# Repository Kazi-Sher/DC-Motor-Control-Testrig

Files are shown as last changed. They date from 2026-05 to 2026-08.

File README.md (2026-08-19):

# DC Motor Control Test Rig

A low-cost open-source experimental test rig for DC motor characterization and embedded control. The rig supports reproducible experiments from basic motor modeling to advanced control design.

## Repository Layout
```text
hardware/       Hardware datasheets, wiring diagram, and rig image
firmware/       STM32 firmware, generated embedded code, board-level configuration
matlab/         MATLAB scripts/Simulink models for identification, validation, control
data/           Raw and processed experiment data used to reproduce plots/metrics
results/        Result plots
```

## Roadmap
- [x] Hardware rig assembled
- [x] Position and speed based model validation
- [x] PI speed control
- [x] State-space position control (pole placement + LQR)
- [x] Observer-based estimation (Luenberger + Kalman / LQG)
- [x] Controller comparison (PID, observer-based pole placement, and LQG)

## Test Rig
- STM32 Nucleo-F446RE microcontroller board
- 12 V DC geared motor with quadrature encoder, JGA25-371 class
- IBT-2 / BTS7960 H-bridge motor driver
- ACS712 5 A current sensor
- 12 V DC power supply

<p align="center">
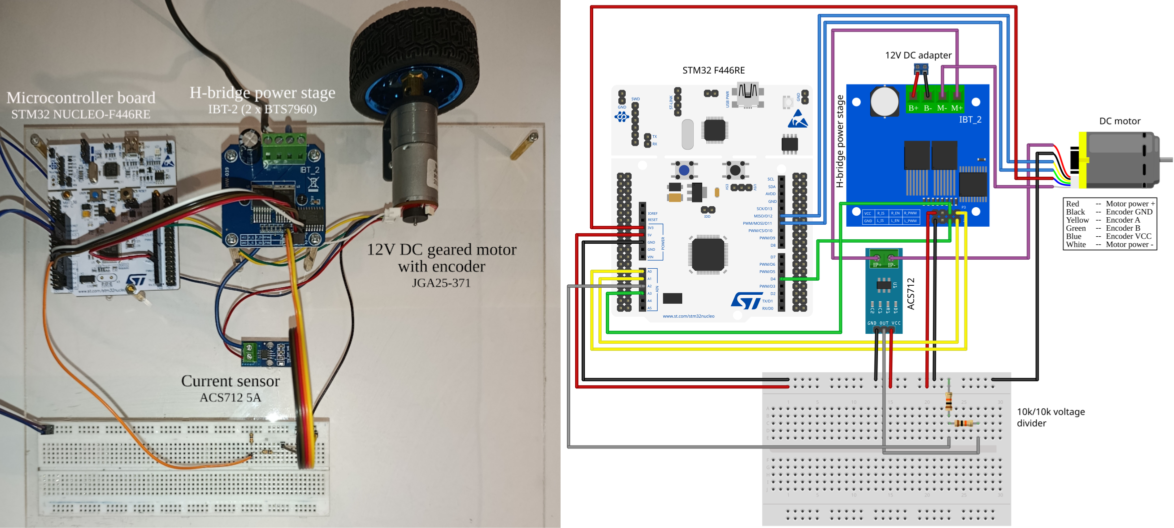
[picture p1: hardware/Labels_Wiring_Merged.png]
Labeled DC motor control test rig
  
</p>

## Motor Identification and Model Validation

Motor parameters were identified by classical lumped-element methods: `R_a` from locked-rotor current; `K` and `b` from steady-state voltage–speed and torque–speed measurements; `J` from a coast-down test.

| Parameter | Value | Note |
|---|---:|---|
| `Ra` | 2.1 Ω | Armature resistance |
| `La` | 100 µH | Armature inductance (assumed for now) |
| `K` | 0.59 V s/rad | Back-EMF / torque constant (output-shaft referred) |
| `J` | 2.03e-3 kg m² | Equivalent inertia (output-shaft referred) |
| `b` | 0.0164 N m s/rad | Viscous friction (output-shaft referred) |

Using these parameters, the model closely matches the measured position response for the voltage-step validation test (`NRMSE = 0.955`, `R^2 = 0.998`).

<p align="center">
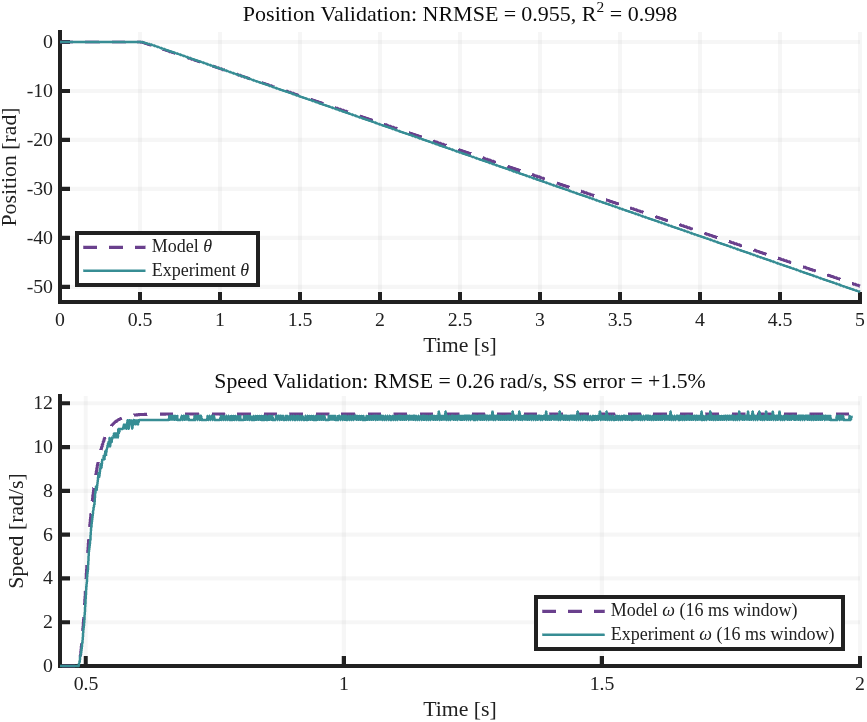
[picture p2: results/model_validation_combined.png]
Open-loop position and speed model validation
  
</p>

The motor was further characterized using an open-loop duty staircase. The identified model was then validated on a separate single-step experiment: a `0.6` duty command applied at `t = 0.5 s`. The model predicts the measured speed response closely:

- RMSE over the step response: `0.26 rad/s`
- Steady-state speed error: `+1.5%`
- Speed estimate: encoder position forward difference with 16 ms window

## PI Speed Control

PI speed control was designed using the experimentally identified first-order speed model of motor:

$$
G(s)=\frac{K_{dc}}{\tau s+1}
$$

where $K_{dc} = 19.524~\text{rad/s/duty}$ and $\tau=0.018~\text{s}$. The controller gains were selected by matching the closed-loop denominator to a second-order target with $\omega_n=50~\text{rad/s}$ and $\zeta=0.9$, giving $K_p = 0.0318$ and $K_i = 2.3049$.

The figure below compares the saturation-aware simulation with the real motor-rig response for a $10~\text{rad/s}$ speed step. The raw embedded speed estimate is shown for transparency, but performance metrics are computed from a 50 ms angle-slope estimate to reduce encoder quantization effects.

Angle-derived experimental metrics:

- Peak speed: $10.51~\text{rad/s}$
- Overshoot: 5.1%
- Rise time: $44~\text{ms}$
- Settling time (2%): $127~\text{ms}$
- Steady-state error: Approx. $3.5e-4~\text{rad/s}$

<p align="center">
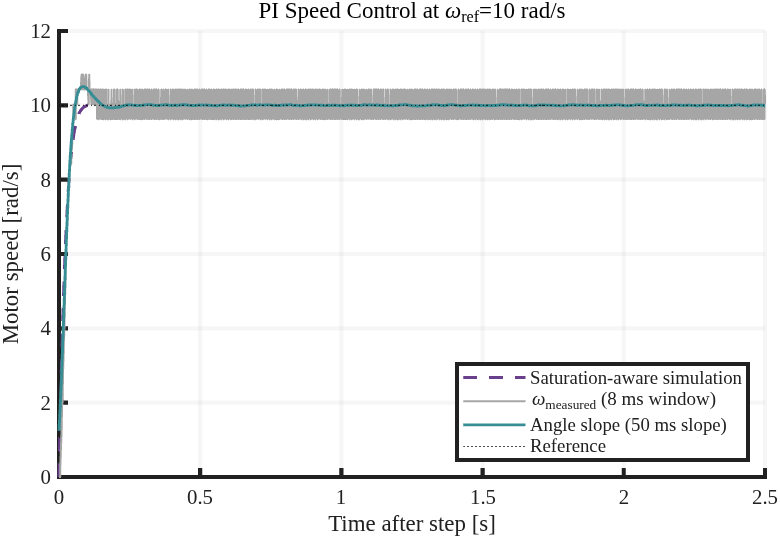
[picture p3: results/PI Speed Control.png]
PI Speed Control
  
</p>

## State-Space Position Control

The PI speed plant was extended to a 2-state position model `x = [θ, ω]ᵀ` and a 3-state form `x_aug = [x_i, θ, ω]ᵀ` with an integrator on the tracking error. Three controller families were designed and deployed with references of 0.20 rad and 0.50 rad:

1. **2-state pole placement (PP2):** `K = [K_θ, K_ω]` plus feedforward `Nbar`
2. **3-state pole placement with integrator (PP3):** `K_aug = [K_i, K_θ, K_ω]`, no `Nbar` since the integrator handles DC tracking
3. **LQR** on the same 3-state plant: gains from `lqr(A_aug, B_aug, Q, R)`

### Pole placement (PP): dead-zone discovery and integrator fix

Without the integrator, the controller stalls before reaching the reference because the residual duty falls below the motor's static-friction threshold. Adding an integrator state eliminates this offset and the saturation-aware simulation tracks the 3-state hardware response within the noise floor.

<p align="center">
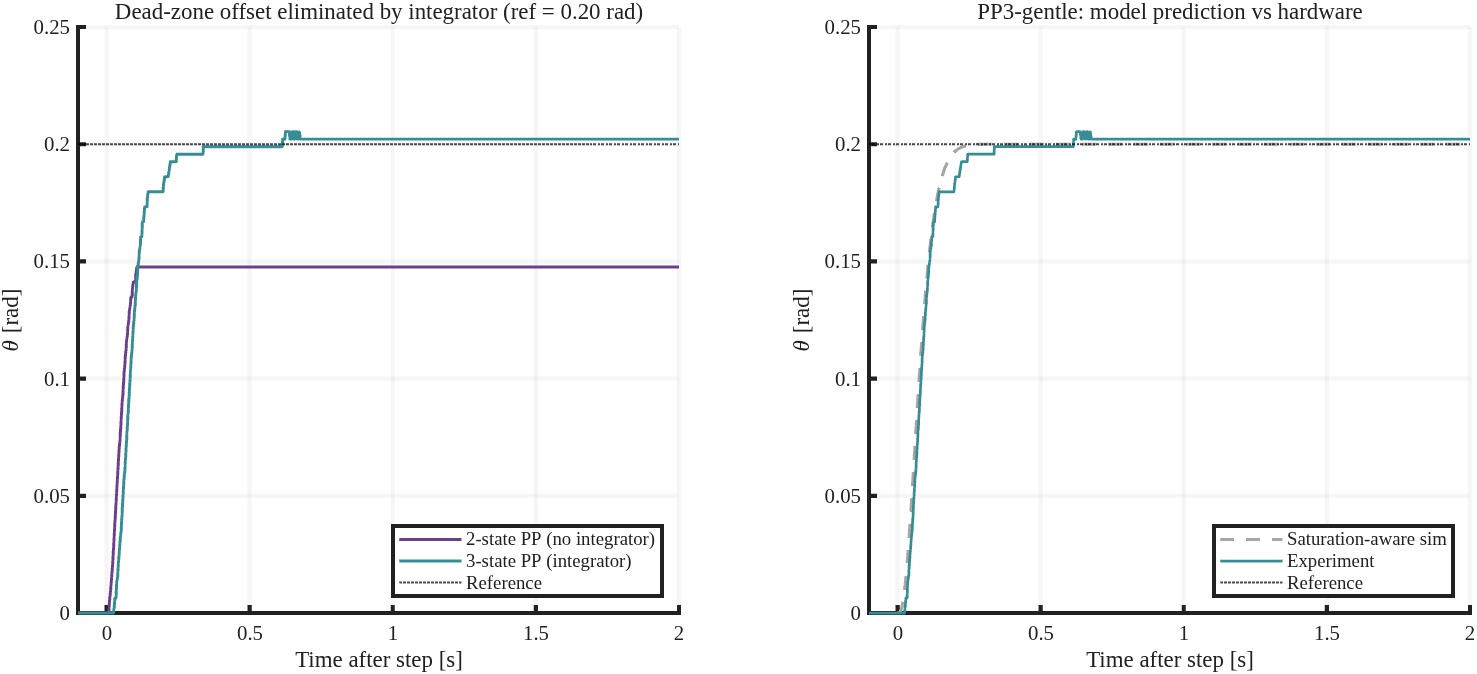
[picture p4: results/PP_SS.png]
State-space pole placement: dead-zone and integrator fix; model vs hardware
  
</p>

Results (reference = 0.20 rad):

- **2-state PP-gentle:** steady-state offset ≈ **26 %** (motor stalls at 0.148 rad)
- **3-state PP-gentle:** steady-state offset ≈ **1 %** (reaches 0.20 rad)
- **Cross-validated motor breakaway threshold:** ≈ **6 % PWM duty**, from residual steady-state command across four PP2 runs
- **Model vs hardware (PP3-gentle):** steady-state match within encoder resolution

### LQR: methodology comparison and a limit-cycle finding

LQR on the same plant chooses gains by minimizing a quadratic cost rather than placing specific poles. Conservative weights produce a clean, low-jitter response but at much lower bandwidth than the equivalent pole-placement design. Aggressive weights raise the bandwidth. But on hardware, the closed loop falls into a sustained limit cycle: position still tracks the reference, but the control effort thrashes between duty saturation rails.

<p align="center">
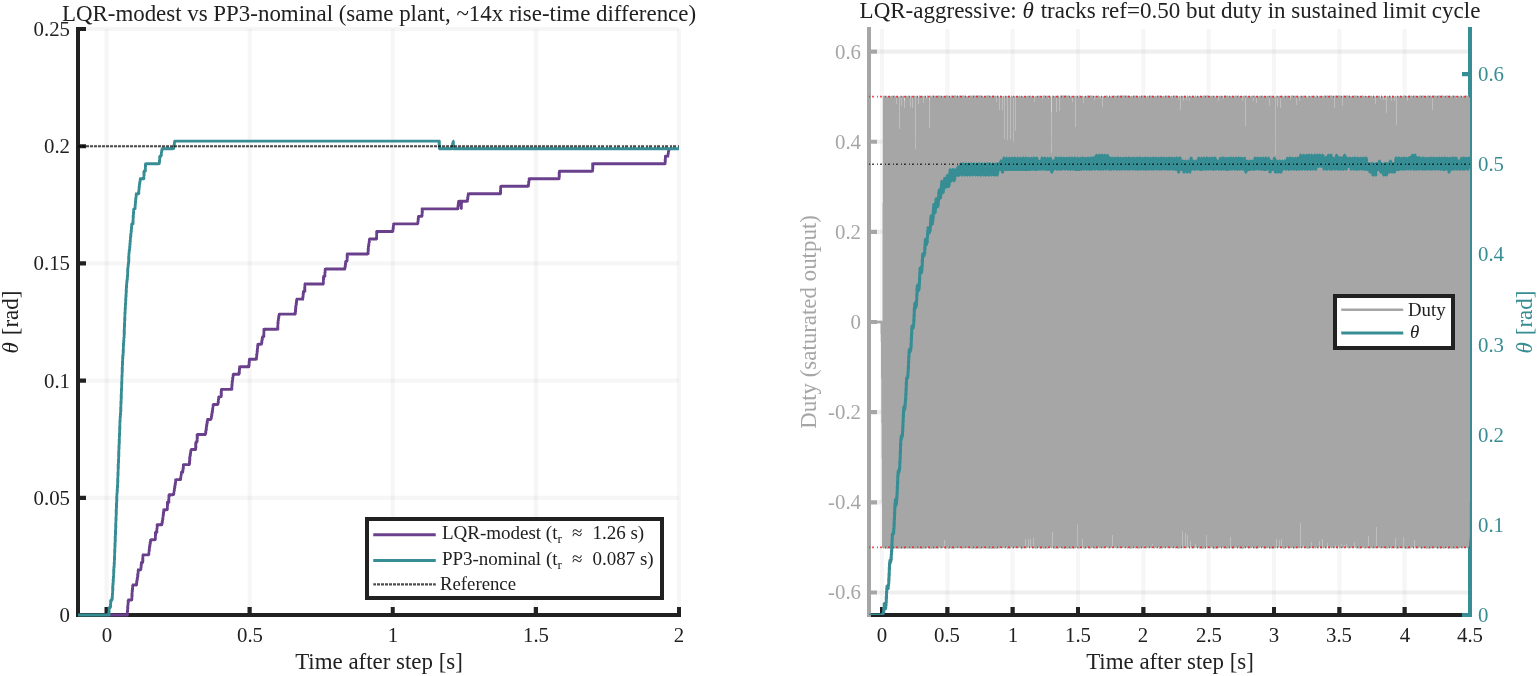
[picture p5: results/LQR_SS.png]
State-space LQR: bandwidth tradeoff and limit-cycle finding
  
</p>

Results:

- **LQR-modest (ref 0.20 rad):** 10–90 rise time ≈ **1.26 s** vs PP3-nominal's **0.087 s** with comparable steady-state accuracy but ~14× slower bandwidth.
- **LQR-aggressive (ref 0.50 rad):** position σ over last 1 s ≈ **5 mrad**, but duty σ ≈ **0.47** with peaks at the ±0.50 saturation rails; peak current ≈ **4.4 A**. The linear-optimal design did not account for encoder quantization, motor dead-zone, duty saturation, and high feedback gains interacting on real hardware.

### Luenberger observer: model-based speed feedback

A discrete Luenberger observer was added to the 3-state pole-placement position controller. The observer estimates `x = [theta, omega]^T` from commanded duty and encoder position; it does not differentiate the encoder signal for speed. The controller gains are unchanged from the PP3-nominal design (`K = [-103.7, 6.04, 0.073]`); only the speed-feedback source is switched between the filtered encoder derivative (`omega_meas`) and observer estimate (`speed_hat`).

<p align="center">
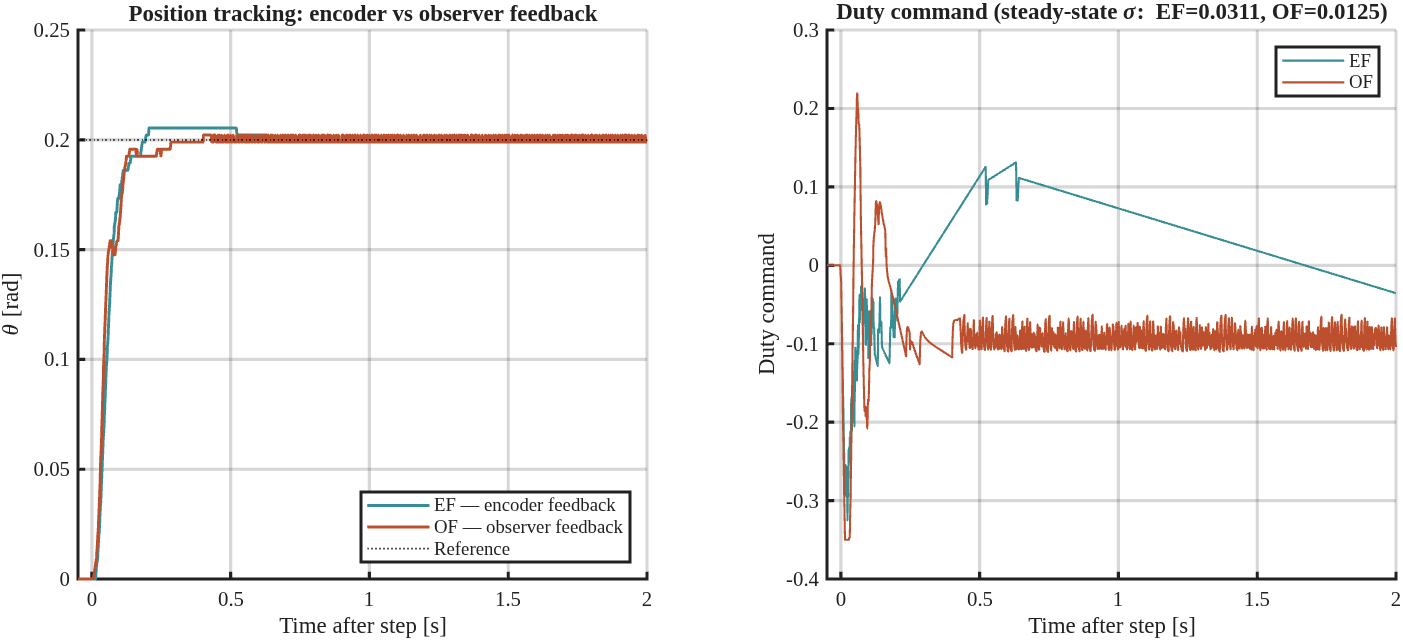
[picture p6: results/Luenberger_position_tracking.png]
Luenberger observer feedback: position tracking and duty command
  
</p>

Results for a `0.20 rad` position step:

- **Observer feedback:** mean steady-state position `0.20000 rad` vs `0.1990 rad` with encoder-speed feedback; both are sub-encoder-count errors, but observer feedback brings the mean error close to zero.
- **Overshoot:** `1.1%` with observer feedback vs `2.7%` with encoder-speed feedback.
- **Rise time:** `92 ms` with observer feedback vs `83 ms` with encoder-speed feedback.
- **Duty ripple:** steady-state duty σ drops from `0.031` to `0.013`; duty peak-to-peak drops from `0.111` to `0.047`.
- **Trade-off:** steady-state position σ rises from `0.15 mrad` to `1.50 mrad`, while peak-to-peak position motion remains bounded to one encoder quantum (`3.21 mrad`).

The observer was also tested with an intentionally incorrect initial speed estimate, `omega_hat(0) = 5 rad/s`.

<p align="center">
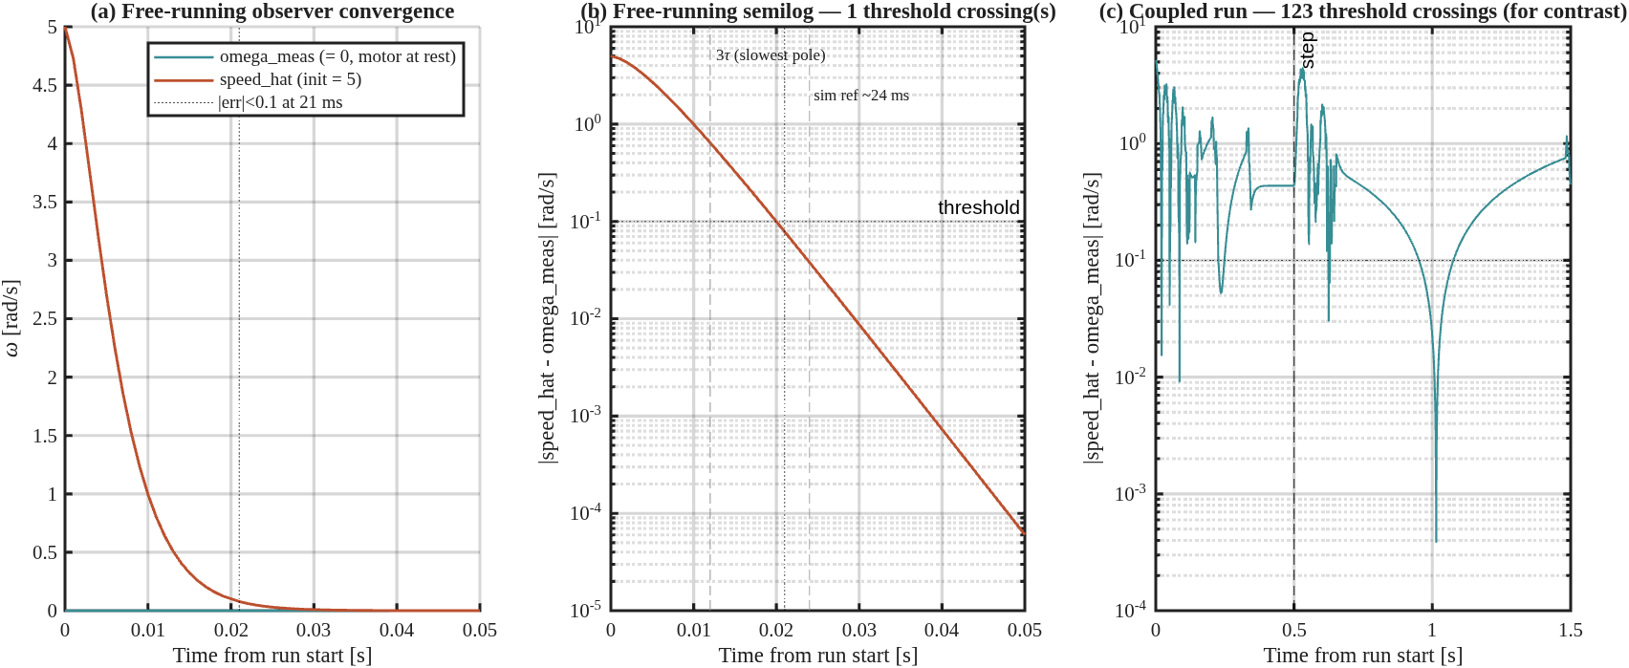
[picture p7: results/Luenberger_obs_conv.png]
Luenberger observer convergence from incorrect initial speed estimate
  
</p>

Convergence results:

- **Decoupled observer test:** encoder feedback remains in control, `ref = 0`, and the motor stays at rest. The observer estimate converges below `0.1 rad/s` in `21 ms` with a single threshold crossing.
- **Coupled observer-in-loop test:** the same incorrect initial estimate is fed to the controller. The controller initially saturates duty and moves the motor, but the closed loop remains stable and recovers to track the reference.

This demonstrates both the estimator's standalone initial-condition recovery and the closed loop's tolerance of observer-state mismatch.

### Kalman estimator (LQG): optimal estimation and a limit-cycle test

The observer architecture was kept identical and only the gain was redesigned: the pole-placement gain `L` was replaced by a steady-state Kalman gain. The measurement-noise covariance `R` is set from encoder quantization (`q²/12`, `q = 3.21 mrad`); the process-noise covariance `Q` is tuned for comparable estimator bandwidth. Paired with the LQR controller, this gives the LQG test case.

<p align="center">
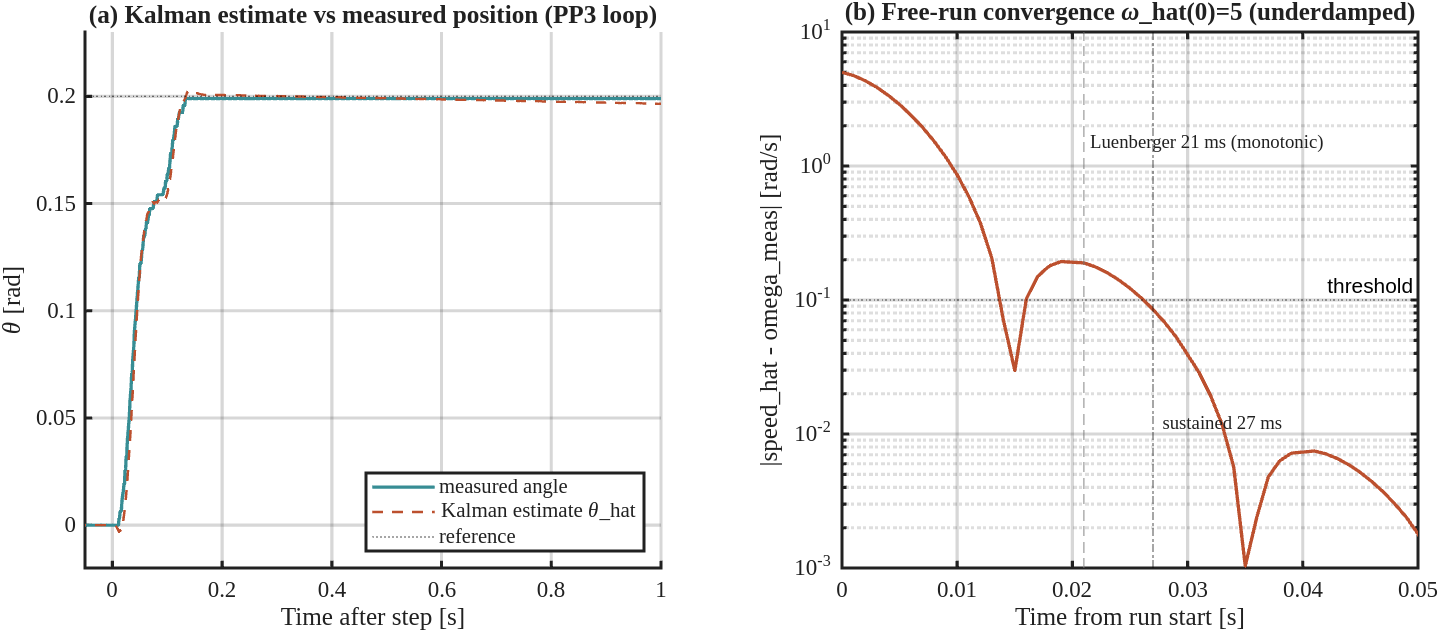
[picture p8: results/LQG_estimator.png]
Kalman estimator: position tracking and free-run convergence
  
</p>

Estimator results (`0.20 rad` step, Kalman estimate feeding the PP3 loop):

- **Tracking:** sub-encoder-count steady-state error and `1.1%` overshoot — on par with the Luenberger result, confirming the Kalman estimator deploys correctly on hardware.
- **Free-run convergence:** with a deliberately wrong initial speed (`omega_hat(0) = 5 rad/s`), controller decoupled, and motor at rest, the Kalman estimate is underdamped. It first crosses `0.1 rad/s` at `14 ms`, then sustains below threshold from `27 ms`; the Luenberger observer was monotonic and reached the same sustained threshold in `21 ms`.

A second test asked whether a cleaner speed estimate could cure the LQR limit cycle found above. The **identical** LQR-aggressive gain was run with the speed feedback switched between the encoder derivative and the Kalman estimate — one signal changed, nothing else (reference `0.20 rad`, duty limit `±0.35`).

<p align="center">
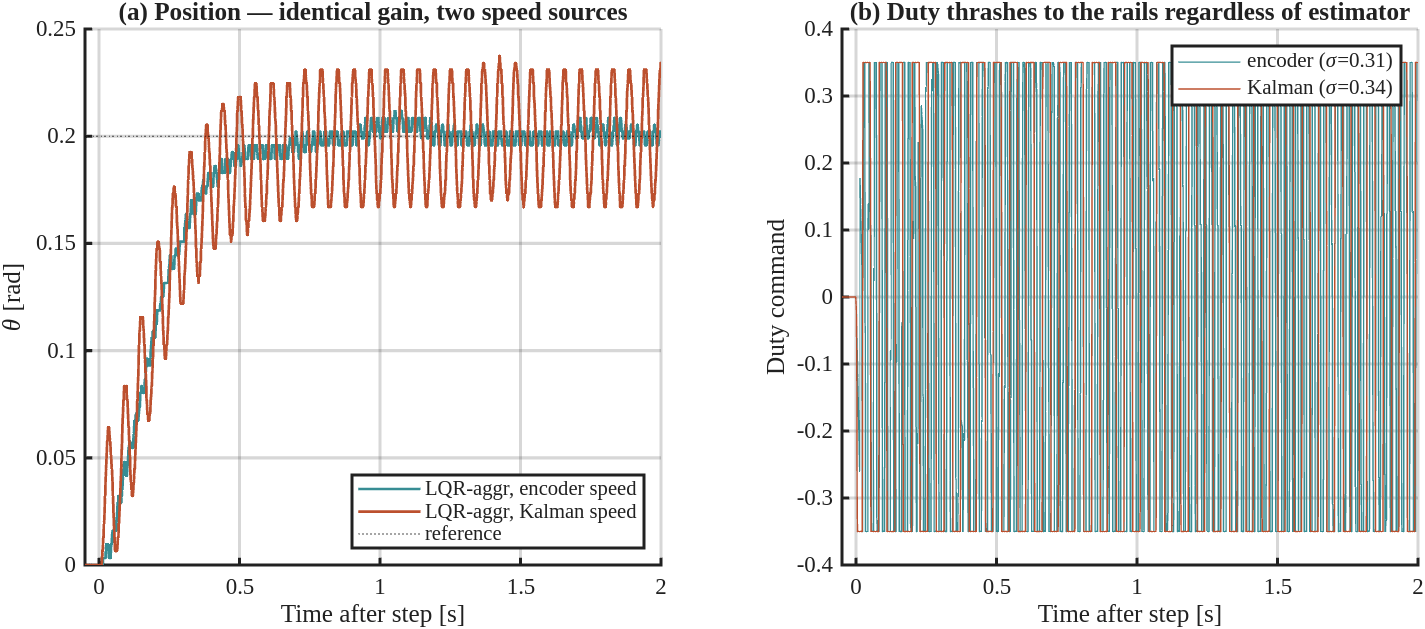
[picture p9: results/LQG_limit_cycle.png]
Limit-cycle test: same LQR gain, encoder vs Kalman speed feedback
  
</p>

Limit-cycle test results:

- The limit cycle **persists with both speed sources**: the duty command thrashes between the `±0.35` saturation rails (steady-state duty `σ ≈ 0.31` with encoder, `0.34` with Kalman) and neither case settles.
- The Kalman estimate **did not suppress** the limit cycle — it amplified the position oscillation (overshoot `5.9% → 18.7%`, peak current `2.85 A → 3.33 A`).
- **Conclusion:** these runs strongly suggest the limit cycle is actuator/dead-zone/saturation driven, not primarily speed-estimate-noise driven. The LQR speed gain `K_ω` is 4–13× the pole-placement value, so replacing the speed estimate alone is not enough; pole placement with observer feedback remains the clean deployable design on this rig.

## Controller Comparison

Four controller configurations were tested using the same `0.20 rad` step input and `±0.35` duty limit: PID, pole placement with Luenberger observer feedback, pole placement with Kalman estimator feedback, and aggressive LQG.

<p align="center">
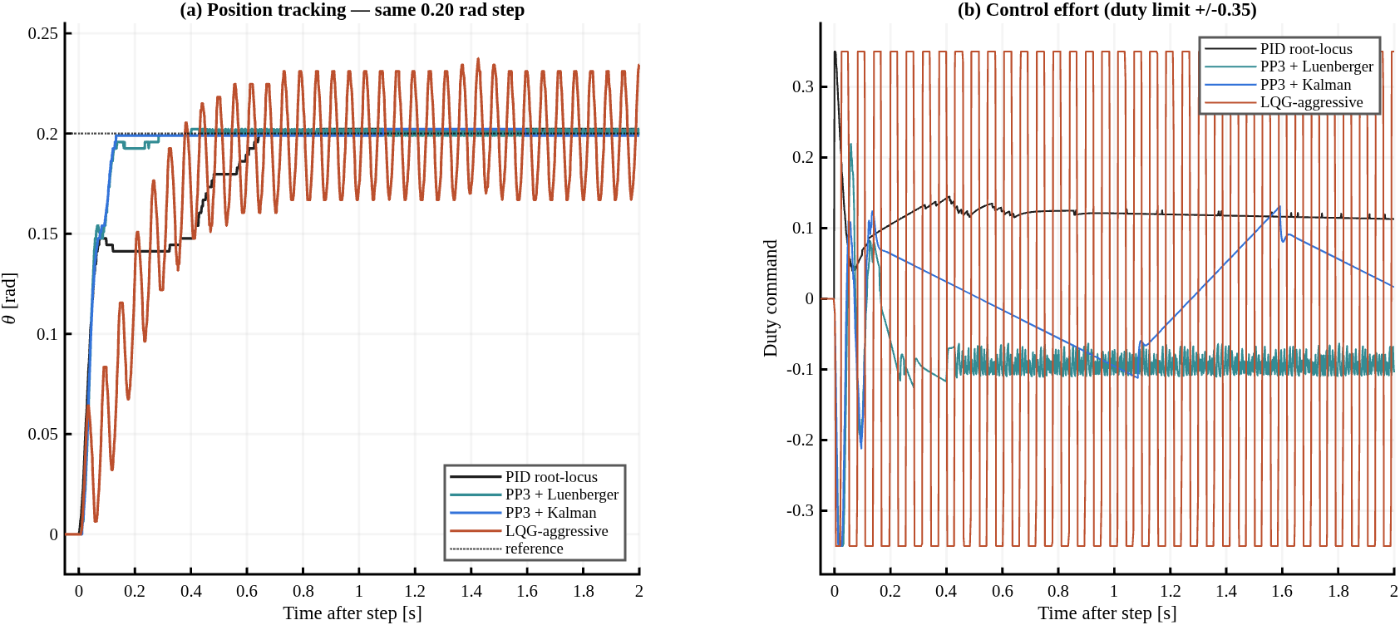
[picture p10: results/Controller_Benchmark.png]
Controller comparison: position tracking and control effort for a common step input
  
</p>

| Controller | Rise `t_r` [ms] | Overshoot [%] | Settling `t_s` [ms] | `e_ss` [mrad] | Duty `σ` | Effort `∫u²dt` | `I_peak` [A] |
|---|---:|---:|---:|---:|---:|---:|---:|
| PID (classical) | 550 | 1.1 | 641 | −1.1 | 0.003 | 0.06 | 1.94 |
| PP3 + Luenberger | 92 | 1.1 | 284 | 0.01 | 0.013 | 0.04 | 1.65 |
| PP3 + Kalman (LQG est.) | 90 | 1.1 | 132 | 0.26 | 0.028 | 0.02 | 1.97 |
| LQG-aggressive (optimal-control gain + Kalman) | 299 | 18.7 | — * | −0.35 | 0.342 | 0.53 | 3.33 |

<sub>* never settles within `±2%`: sustained limit cycle. Steady-state stats over the final 1 s; encoder quantum = 3.21 mrad.</sub>

- **PID** tracks cleanly to sub-quantum error but is ~6× slower, climbing in a visible dead-zone staircase, at the lowest control effort.
- **Pole placement with observer feedback** is the best overall design: ~`90 ms` rise, sub-quantum steady-state error, and the lowest control effort. The observer choice is a minor trade — Luenberger settles with lower duty `σ`, Kalman settles fastest.
- **LQG-aggressive** overshoots and never settles; the dead-zone/saturation limit cycle dominates at ~10–17× the control effort and ~2× the peak current of the observer-based designs.

The headline result: on this rig, **modern observer-based pole placement is the deployable winner.** Better state *estimation* (Luenberger → Kalman) improves the feedback signal, but textbook-optimal *control* (LQR) requires explicit dead-zone / anti-windup handling before it is usable — a practical lesson that only the hardware experiment reveals.

## Citation

If you use this project or build on the test rig design, please cite:

```bibtex
@misc{ahmed2026dcmotorcontroltestrig,
  title        = {DC Motor Control Test Rig},
  author       = {Ahmed, Kazi Sher},
  year         = {2026},
  howpublished = {\url{https://github.com/Kazi-Sher/DC-Motor-Control-Testrig}},
  note         = {Open-source hardware and control test rig}
}
```

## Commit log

2026-04-17 Rename MotorRig.fzz to source_files/MotorRig.fzz
    Wiring diagram prepared in Fritzing
    [MotorRig.fzz]
2026-05-30 Renamed motor datasheet
2026-11-10 Motor video embed
